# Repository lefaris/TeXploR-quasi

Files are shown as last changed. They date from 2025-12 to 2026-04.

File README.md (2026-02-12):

# TeXploR-quasi




This repository contains the system design documentation and quasistatic simulation for **TeXploR2** (Tensegrity eXploratory Robot 2), a curved-link tensegrity robot capable of dynamic rolling locomotion through internal mass shifting. This work represents a significant advancement over the [original TeXploR](https://github.com/lefaris/TeXploR-geometric).  This repo is supplemental for **System Design of Tensegrity Robot Exhibiting Non-Intuitive Behavior** accepted to IEEE ICRA 2026.

---

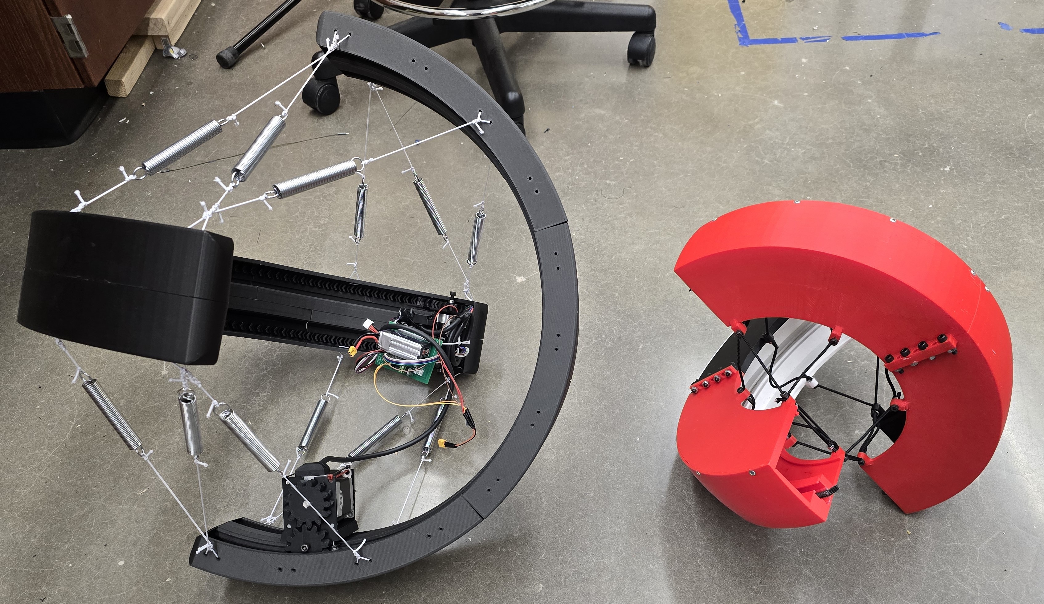
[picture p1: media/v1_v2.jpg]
TeXploR2 Comparison

*TeXploR2 (left, black) compared to the original TeXploR (right, red). TeXploR2 is completely redesigned for smoother dynamic movement regardless of shifting mass orientation (e.g., hanging upside down). The prototype is also significantly larger for additional central payload capabilities.*

## Overview

TeXploR2 is a curved-link tensegrity robot that achieves efficient rolling while maintaining stability through discontinuities present at arc endpoints. Unlike traditional straight-link tensegrity robots that contain slower toppling/walking locomotion gaits, TeXploR2's spherical-like design enables rolling.

### Key Contributions

This work showcases the system design for the TeXploR2 prototype. We also introduce non-intuitive state switching behavior that enables state transitions without requiring the shifting mass to reach arc endpoints. This enables faster state jumping and trajectory control.

- **Updated System Design**: More robust prototype capable of real-time tetherless locomotion
- **Non-Intuitive Control**: Efficient state jumping achievable along boundary lines
- **Shock Absorption**: Compliant tensegrity structure withstands impacts
- **Modular Modeling Framework and Design**: Scalable to additional curved links for finer control

---
## Demos

### Shifting Mass
TeXploR2 Shifting Mass

### Rolling Locomotion
TeXploR2 Rolling

### Impact Test
Impact Side View
Impact Other Side View

---

## Repository Structure

```
TeXploR-quasi/
├── quasistatic_modeling/   # MATLAB quasistatic simulation code
│   └── visualization/      # Simulation visualization
├── experiments/            # Motion capture data and test scripts
├── design_files/           # TeXploR2 design files
│   ├── CAD/                # Fusion files
│   └── PCB/                # KiCAD files
└── figures/                # Demo figures/videos
```

---

## Getting Started

### Prerequisites

- MATLAB R2020b or later
- Optional: Python 3.x (for hardware integration)

### Installation

1. **Clone the repository**
   ```bash
   git clone https://github.com/lefaris/TeXploR-quasi.git
   cd TeXploR-quasi
   ```

2. **Set up MATLAB path**
   ```matlab
   addpath(genpath('quasistatic_modeling'))
   ```

3. **Run quasistatic simulation**
   ```matlab
   cd quasistatic_modeling
   run('TExploRStaticsDerivationsQuasi3(0, 90)')
   ```

---

## System Design

### Mechanical Properties

| Component | Specification |
|---|---|
| **Arc Diameter** | 585mm (vs. 403mm TeXploR v1) |
| **Arc Width** | 98mm (vs. 83mm TeXploR v1) |
| **Arc Mass** | ~1,300g each |
| **Shifting Mass** | 1,150g each |
| **Mass Ratio** | 0.88:1 (shifting:arc) |
| **Material** | Onyx (Markforged) |

### Electronics

- **Controller**: Raspberry Pi Zero 2W
- **Motors**: Dual-shaft NEMA23 bipolar stepper motors (200 steps/rev)
- **Motor Drivers**: TB67S128FTG high-current carriers
- **Sensors**: 9-axis IMU (I2C)
- **Power**: 11.4V 1.5Ah LiPo battery
- **Control**: Open-loop with SSH remote control
- **Board**: Custom PCB

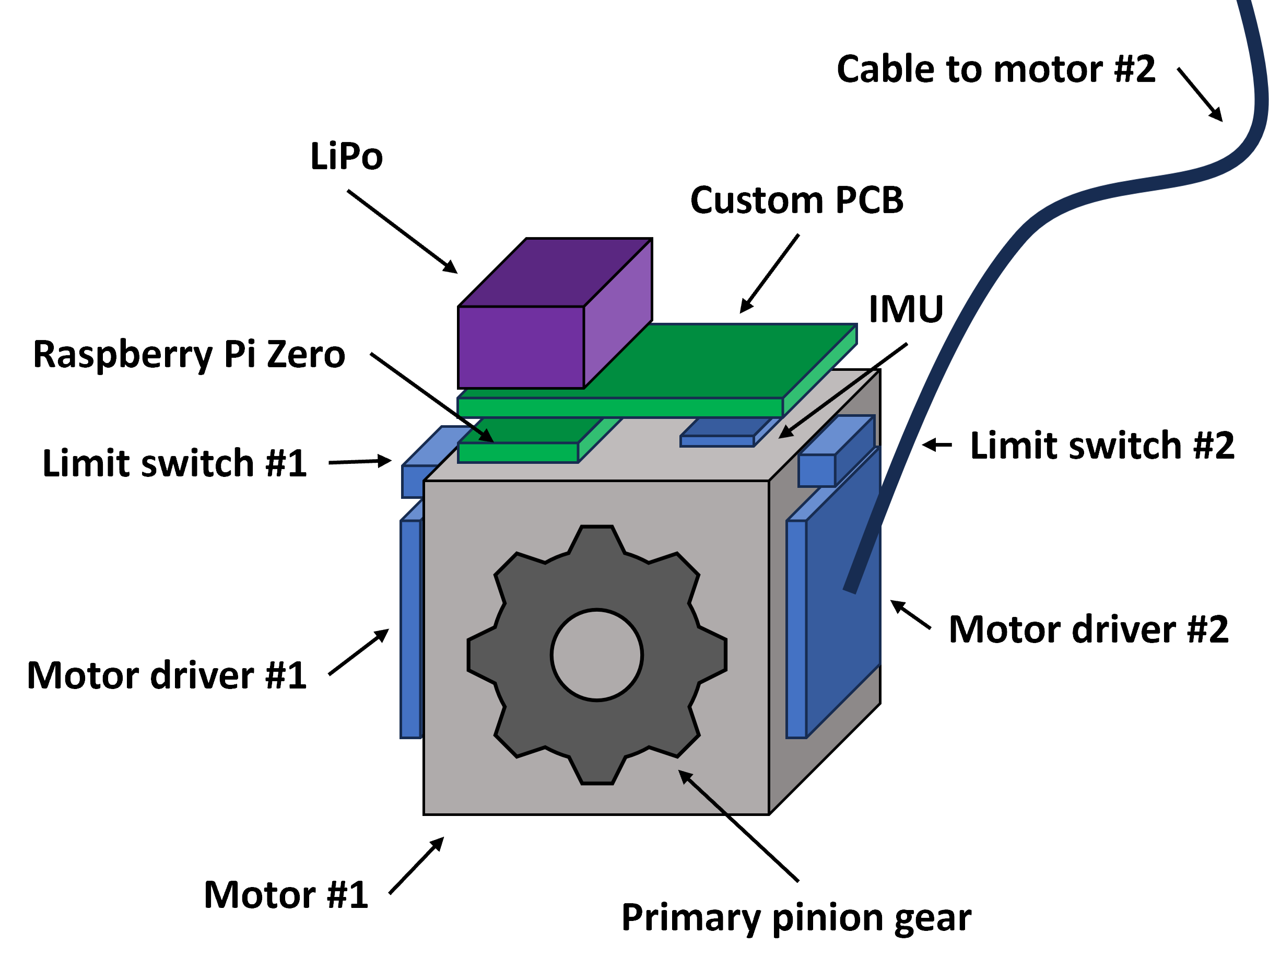
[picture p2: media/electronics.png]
TeXploR2 Electronics


### Motor Carriage Design

- **T-track latching**: For precise alignment
- **8 v-groove bearings**: (4 horizontal, 4 vertical) to prevent rotation and maintain grip
- **6 ball bearings**: For smooth rolling along arc curvature
- **Herringbone gear teeth**: For smooth power transmission at high loads

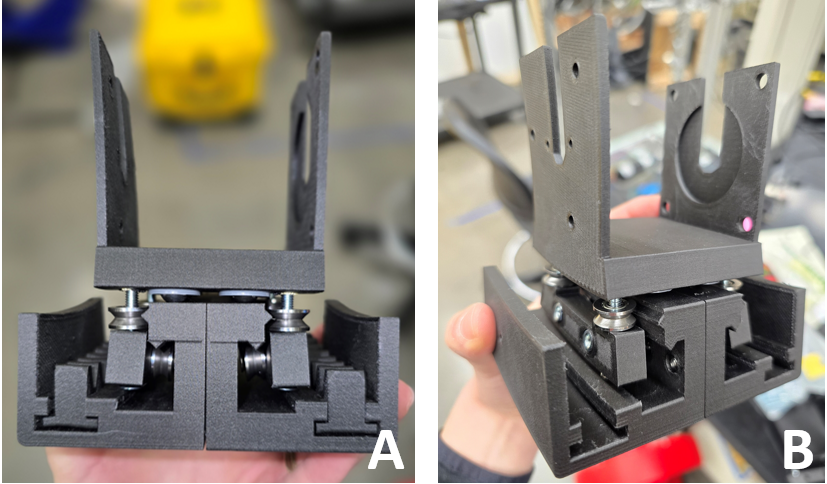
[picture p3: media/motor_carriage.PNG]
Motor Carriage


### Arc Design

- **Dual internal gear racks**: Parallel along inner curvature
- **Matching Pinion gears**: Driven by dual-shaft NEMA23 motor
- **Symmetric mass distribution**: Minimizes model discrepancies
- **98mm width**: Minimum for NEMA23 integration

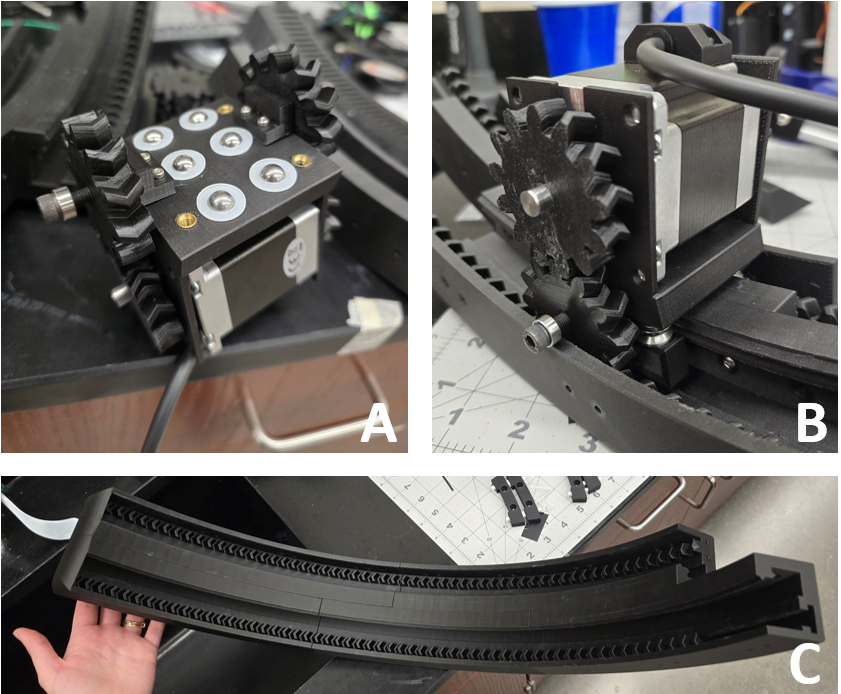
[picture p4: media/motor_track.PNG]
Motor Track


---

## Citation

If you use this work in your research, please cite both papers:

### TeXploR2 (ICRA 2026)

```bibtex
@inproceedings{texplor2_2026,
  title={System Design of Tensegrity Robot Exhibiting Non-Intuitive Behavior},
  author={Ervin, Lauren and Bezawada, Harish and Vikas, Vishesh},
  booktitle={2026 IEEE International Conference on Robotics and Automation (ICRA)},
  year={2026},
  organization={IEEE}
}
```
**arXiv preprint:** [arXiv](https://arxiv.org) (Coming Soon)

### TeXploR Geometric Modeling (IEEE RA-L 2024)

```bibtex
@article{texplor_2024,
  title={Geometric Static Modeling Framework for Piecewise-Continuous Curved-Link Multi Point-of-Contact Tensegrity Robots},
  author={Ervin, Lauren and Vikas, Vishesh},
  journal={IEEE Robotics and Automation Letters},
  year={2024},
  volume={9},
  number={12},
  pages={11066-11073},
  doi={10.1109/LRA.2024.3486199}
}
```

---

## Updates

- **January 2026:** Paper accepted to IEEE ICRA 2026
- **September 2025:** Version 2 of [TeXploR robot design](https://github.com/lefaris/TeXploR-geometric) submitted to IEEE ICRA 2026

---

## License

This project is released for academic and research purposes.

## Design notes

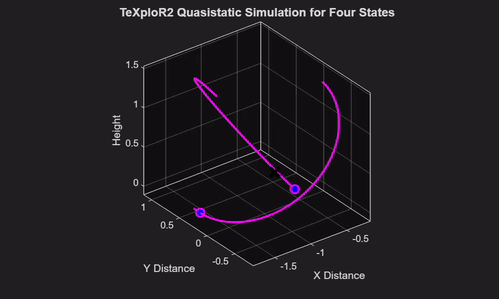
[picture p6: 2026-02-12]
quasistatic_modeling/visualization/quasiIntuitive.gif

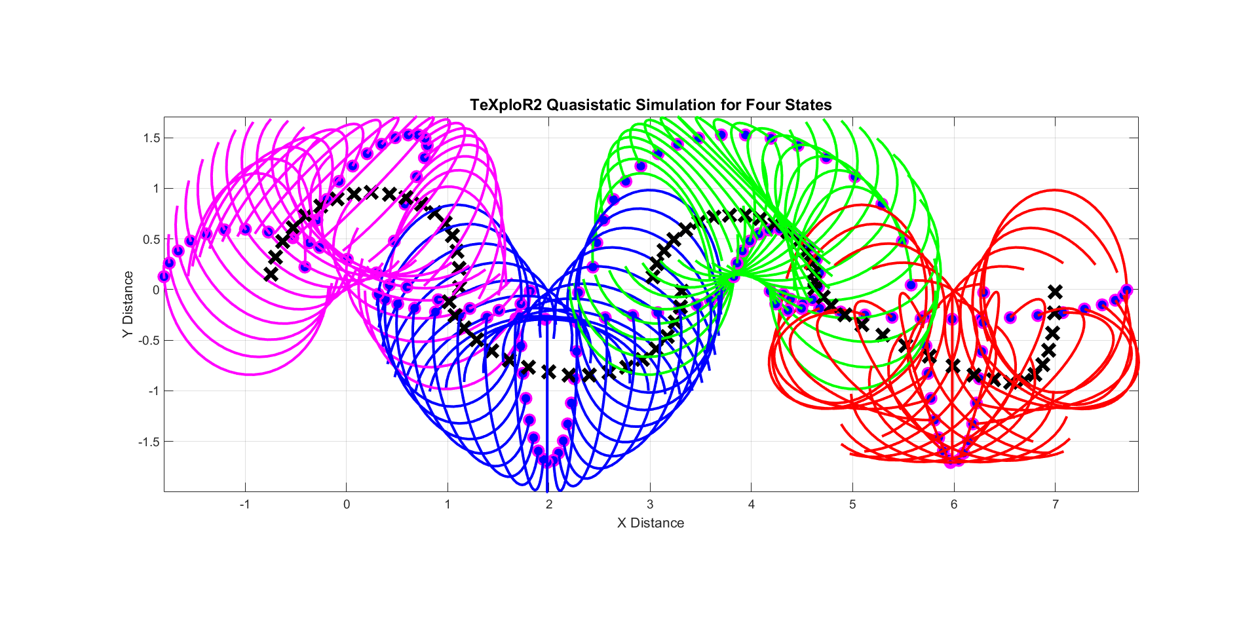
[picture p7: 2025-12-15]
quasistatic_modeling/visualization/quasi3_view2.png

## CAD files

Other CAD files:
design_files/CAD/double_helical_gear.f3d

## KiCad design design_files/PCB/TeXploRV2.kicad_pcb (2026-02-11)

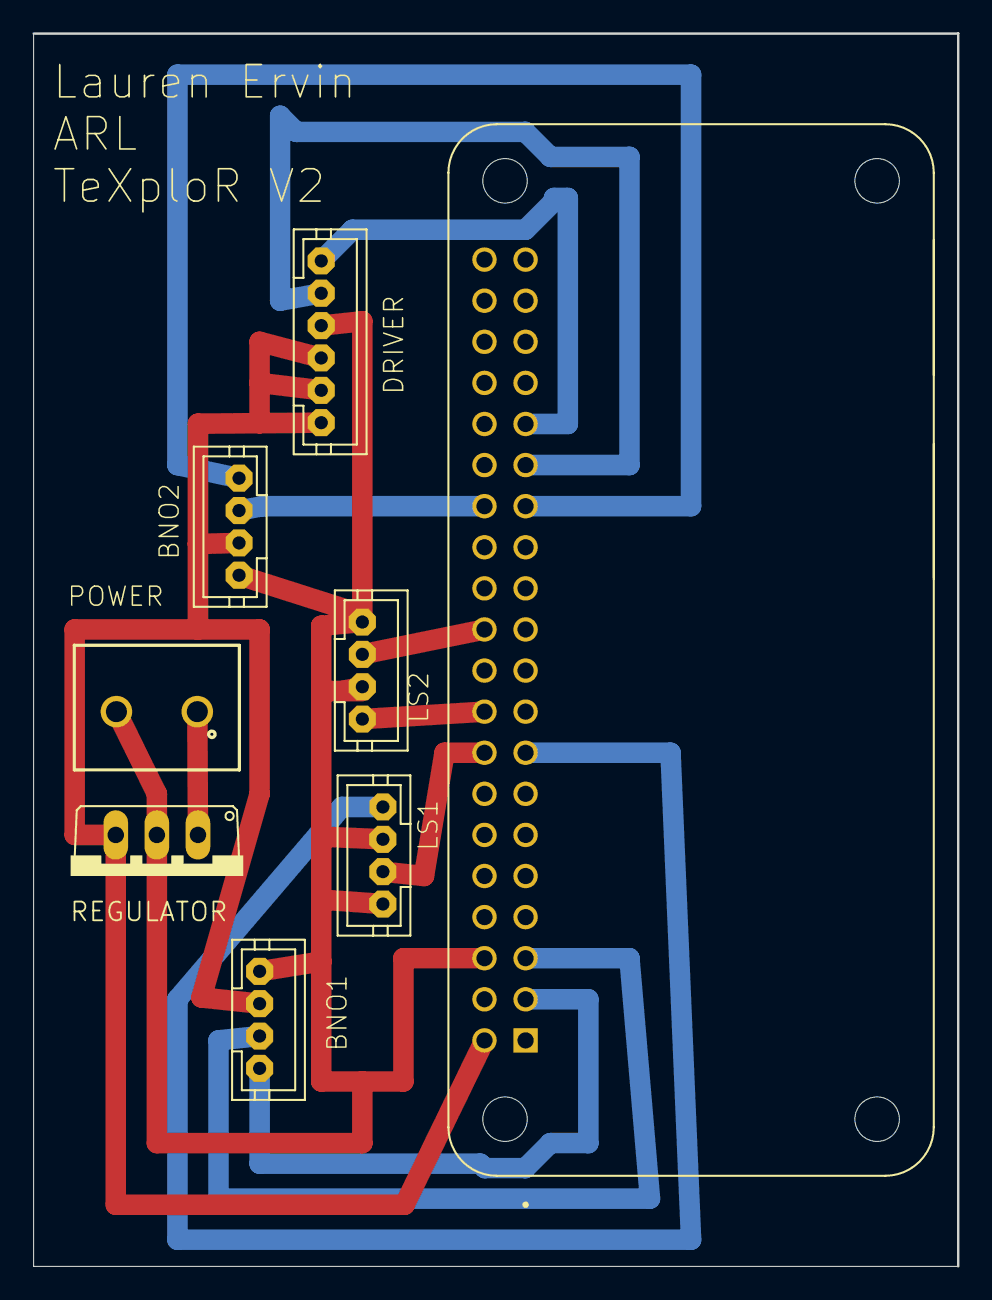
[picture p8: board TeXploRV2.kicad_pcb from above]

Board: 2 copper layers, 57.1 x 76.2 mm, 8 parts (0 on the bottom side), 13 nets.

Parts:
BNO1, BNO2: JST-PH4
DRIVER: JST-PH6
LS1, LS2: JST-PH4
POWER: 691137710002; 691137710002_16177944
REGULATOR: 7805TV; TO220V_262
U1: RASPBERRY_PI_ZERO_2_W; MODULE_RASPBERRY_PI_ZERO_2_W

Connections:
5V: BNO1.3, BNO2.3, DRIVER.1, DRIVER.2, DRIVER.3, REGULATOR.3, U1.2
DIR: DRIVER.5, U1.29
GND: BNO1.4, BNO2.4, DRIVER.4, LS1.2, LS1.4, LS2.2, LS2.4, POWER.2, REGULATOR.2, U1.6
GPIO22: LS1.1, U1.15
GPIO23: LS1.3, U1.16
GPIO24: LS2.1, U1.18
GPIO25: LS2.3, U1.22
SCL1: BNO1.2, U1.5
SCL2: BNO2.2, U1.28
SDA1: BNO1.1, U1.3
SDA2: BNO2.1, U1.27
STEP: DRIVER.6, U1.31
VIN: POWER.1, REGULATOR.1

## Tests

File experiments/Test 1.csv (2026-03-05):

Timestamp | Quat_I | Quat_J | Quat_K | Quat_Real | Acceleration_X | Acceleration_Y | Acceleration_Z
14:55.7 | 0 | 0 | 0 | 0 | 0.69140625 | -8.42578125 | 5.25
14:55.7 | 0 | 0 | 0 | 0 | 0.69140625 | -8.42578125 | 5.25
14:55.7 | 0 | 0 | 0 | 0 | 0.69140625 | -8.42578125 | 5.25
14:55.7 | 0 | 0 | 0 | 0 | 0.69140625 | -8.42578125 | 5.25
14:55.7 | 0 | 0 | 0 | 0 | 0.69140625 | -8.42578125 | 5.25
14:55.7 | 0 | 0 | 0 | 0 | 0.23046875 | -8.81640625 | 5.40234375
14:55.7 | 0 | 0 | 0 | 0 | 0.23046875 | -8.81640625 | 5.40234375
14:55.7 | 0 | 0 | 0 | 0 | 0.23046875 | -8.81640625 | 5.40234375
14:55.7 | 0 | 0 | 0 | 0 | 0.23046875 | -8.81640625 | 5.40234375
14:55.7 | -0.101928711 | 0.474975586 | -0.866699219 | 0.11315918 | 0.23046875 | -8.81640625 | 5.40234375
14:55.7 | -0.101928711 | 0.474975586 | -0.866699219 | 0.11315918 | 0.23046875 | -8.81640625 | 5.40234375
14:55.7 | -0.101928711 | 0.474975586 | -0.866699219 | 0.11315918 | 0.23046875 | -8.81640625 | 5.40234375
14:55.7 | -0.101928711 | 0.474975586 | -0.866699219 | 0.11315918 | 0.23046875 | -8.81640625 | 5.40234375
14:55.7 | -0.101928711 | 0.474975586 | -0.866699219 | 0.11315918 | 1.07421875 | -8.390625 | 5.1328125
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

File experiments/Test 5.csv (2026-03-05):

Timestamp | Quat_I | Quat_J | Quat_K | Quat_Real | Acceleration_X | Acceleration_Y | Acceleration_Z
2026-03-04 02:35:42.107155 | 0.0 | 0.0 | 0.0 | 0.0 | 0.53515625 | 9.1171875 | 2.8359375
2026-03-04 02:35:42.111987 | 0.0 | 0.0 | 0.0 | 0.0 | 0.53515625 | 9.1171875 | 2.8359375
2026-03-04 02:35:42.114521 | 0.0 | 0.0 | 0.0 | 0.0 | 0.53515625 | 9.1171875 | 2.8359375
2026-03-04 02:35:42.118206 | 0.0 | 0.0 | 0.0 | 0.0 | 0.53515625 | 9.1171875 | 2.8359375
2026-03-04 02:35:42.120288 | 0.0 | 0.0 | 0.0 | 0.0 | 0.53515625 | 9.1171875 | 2.8359375
2026-03-04 02:35:42.124864 | 0.0 | 0.0 | 0.0 | 0.0 | 0.53515625 | 9.1171875 | 2.8359375
2026-03-04 02:35:42.126877 | 0.0 | 0.0 | 0.0 | 0.0 | 0.53515625 | 9.1171875 | 2.8359375
2026-03-04 02:35:42.136676 | 0.0 | 0.0 | 0.0 | 0.0 | 0.15234375 | 9.23046875 | 2.94921875
2026-03-04 02:35:42.138344 | 0.0 | 0.0 | 0.0 | 0.0 | 0.15234375 | 9.23046875 | 2.94921875
2026-03-04 02:35:42.147141 | 0.59136962890625 | -0.04547119140625 | -0.0164794921875 | 0.804931640625 | 0.15234375 | 9.23046875 | 2.94921875
2026-03-04 02:35:42.148801 | 0.59136962890625 | -0.04547119140625 | -0.0164794921875 | 0.804931640625 | 0.15234375 | 9.23046875 | 2.94921875
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

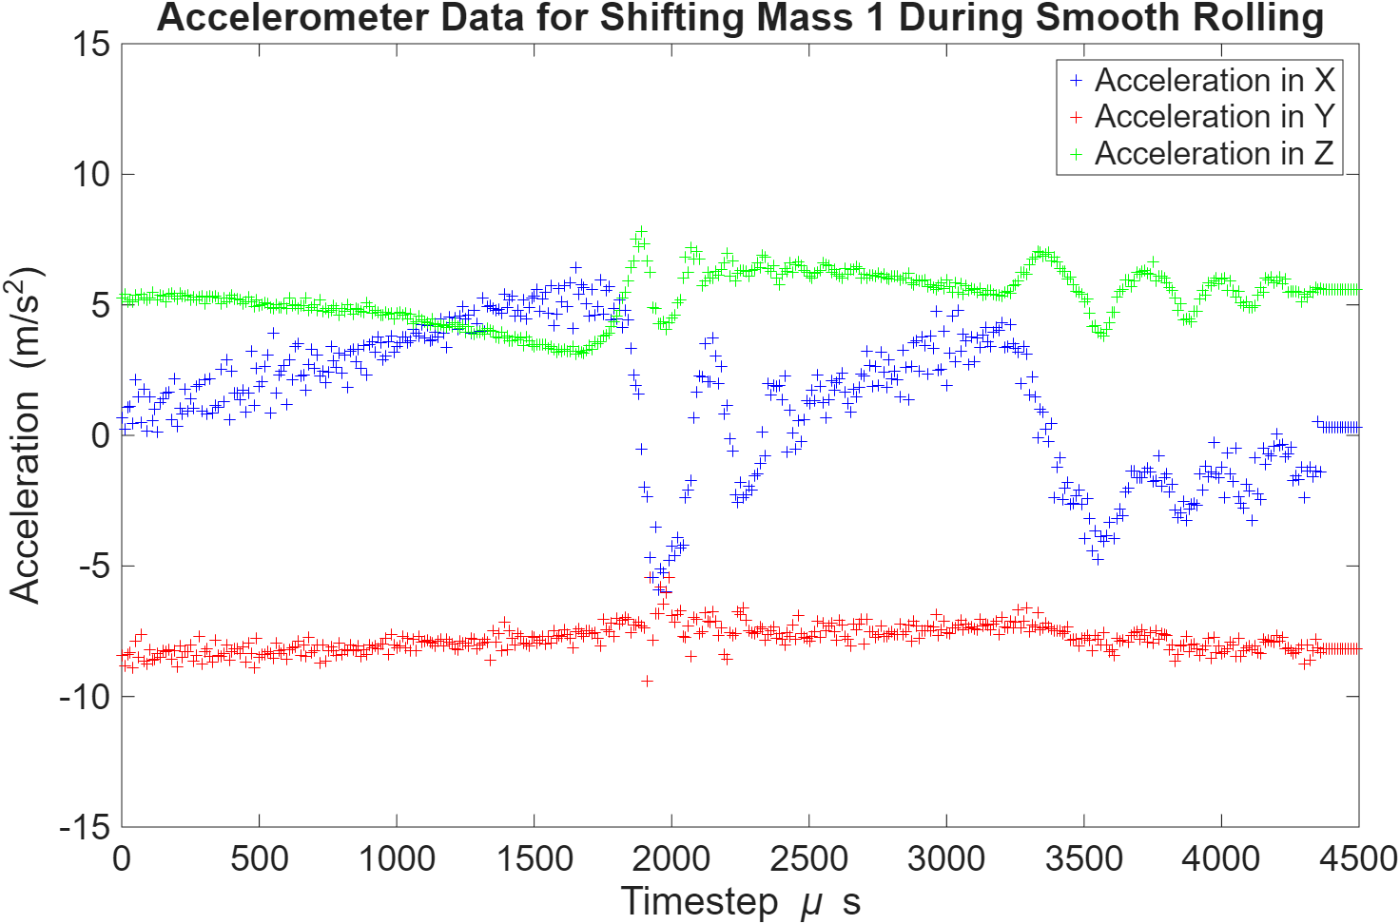
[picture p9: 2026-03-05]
experiments/rolling_accel2.png

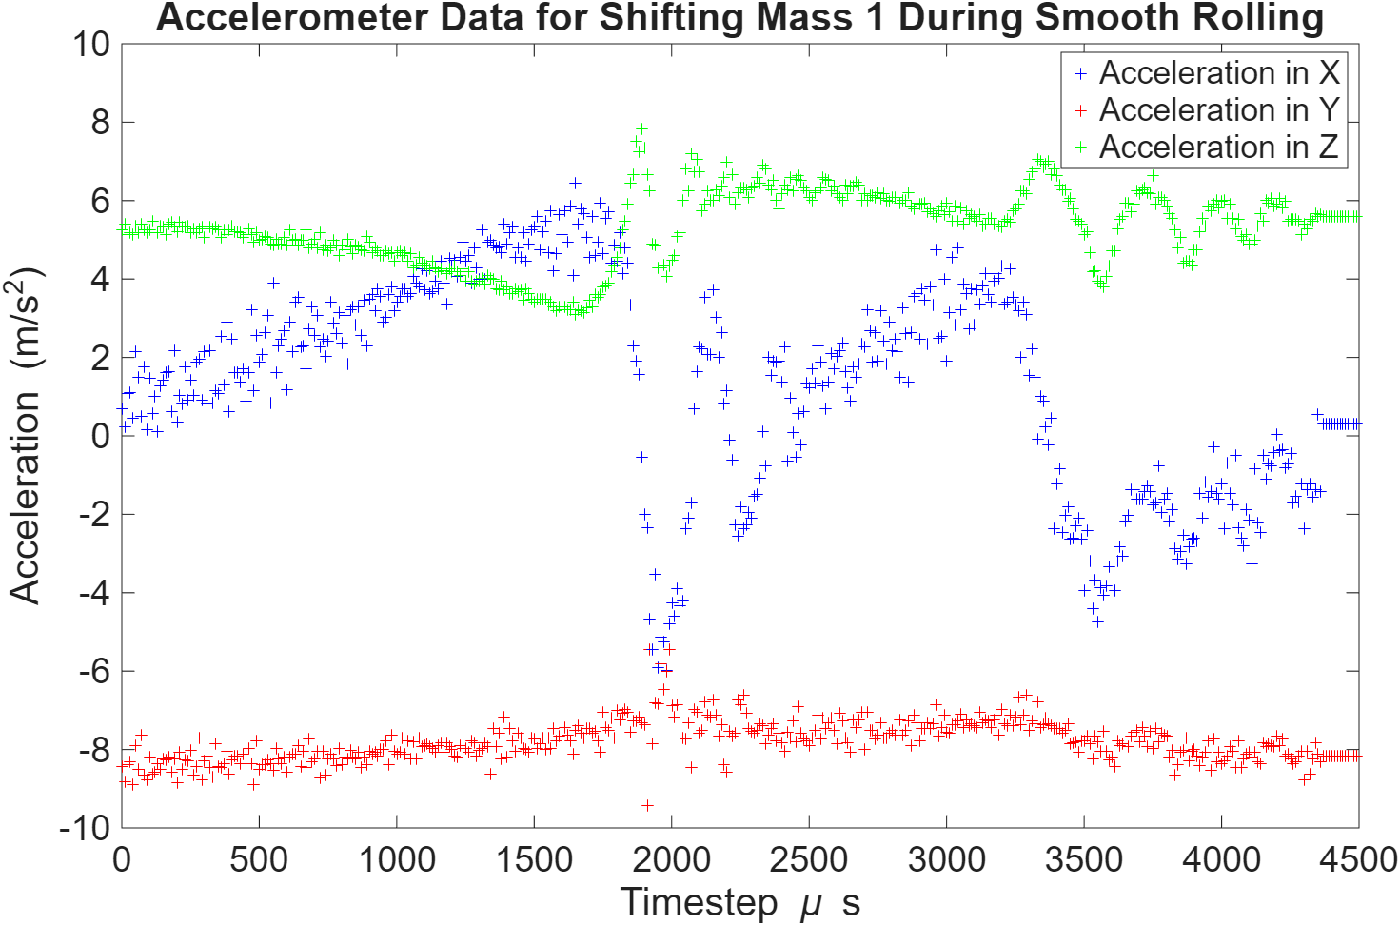
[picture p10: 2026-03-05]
experiments/rolling_accel.png

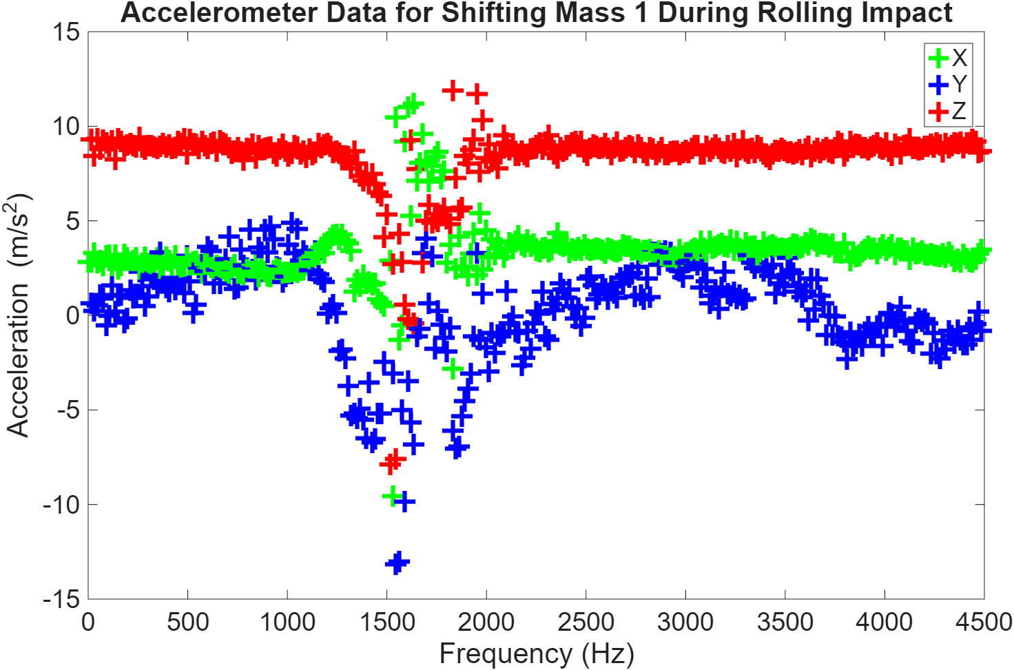
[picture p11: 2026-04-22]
experiments/impact_accel.png

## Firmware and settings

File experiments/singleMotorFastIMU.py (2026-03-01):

# Lauren Ervin
# Faster movement w/ one motor at 
# a time for TeXploR2 w/ 1 IMU

from time import sleep
import datetime
import csv
import board
import busio
from adafruit_bno055 import BNO055_I2C
import RPi.GPIO as GPIO
import os

# Shifting mass 1
DIR = 6
STEP = 5

# Shifting mass 2
DIR2 = 13
STEP2 = 12

# Clockwise/counterclockwise and steps per revolution
CW = 1
CCW = 0
SPR = 200

# GPIO setup
GPIO.setmode(GPIO.BCM)
GPIO.setup(DIR, GPIO.OUT)
GPIO.setup(STEP, GPIO.OUT)
GPIO.setup(DIR2, GPIO.OUT)
GPIO.setup(STEP2, GPIO.OUT)
GPIO.output(DIR, CW)

step_count = SPR*6 # Travel full semi-circular arc
delay = 0.002 # Controls the speed of commands inversely

i2c = busio.I2C(board.SCL, board.SDA)
bno1 = BNO055_I2C(i2c)

# Define the filename - make sure to update for each experiment!
filename = 'bno_TeXploR_test.csv'
fieldnames = ['Timestamp', 'Euler_Roll', 'Euler_Pitch', 'Euler_Yaw', 'Acceleration_X', 'Acceleration_Y', 'Acceleration_Z']

# Write CSV header
def write_header(filename, fieldnames):
    file_exists = os.path.exists(filename) and os.stat(filename).st_size != 0
    with open(filename, 'a', newline='') as csvfile:
        writer = csv.DictWriter(csvfile, fieldnames=fieldnames)
        if not file_exists:
            writer.writeheader()

# Append BNO data
def log_bno_data(filename, fieldnames):
    roll, pitch, yaw = bno.euler
    accel_x, accel_y, accel_z = bno.acceleration
    timestamp = datetime.datetime.now().strftime("%Y-%m-%d %H:%M:%S")

    data = {
        'Timestamp': timestamp,
        'Euler_Roll': roll,
        'Euler_Pitch': pitch,
        'Euler_Yaw': yaw,
        'Acceleration_X': accel_x,
        'Acceleration_Y': accel_y,
        'Acceleration_Z': accel_z
    }

    with open(filename, 'a', newline='') as csvfile:
        writer = csv.DictWriter(csvfile, fieldnames=fieldnames)
        writer.writerow(data)
            
write_header(filename, fieldnames) # Generate header

# Motor 1 travel from 0 to 180
for x in range(step_count):
    GPIO.output(STEP, GPIO.HIGH)
    log_bno_data(filename, fieldnames)
    sleep(delay)
    log_bno_data(filename, fieldnames)
    GPIO.output(STEP, GPIO.LOW)
    log_bno_data(filename, fieldnames)
    sleep(delay)
    log_bno_data(filename, fieldnames)

# Motor 2 travel from 180 to 0
sleep(0.5)
GPIO.output(DIR2, CW)
for x in range(step_count):
    GPIO.output(STEP2, GPIO.HIGH)
    log_bno_data(filename, fieldnames)
    sleep(delay)
    log_bno_data(filename, fieldnames)
    GPIO.output(STEP2, GPIO.LOW)
    log_bno_data(filename, fieldnames)
    sleep(delay)
    log_bno_data(filename, fieldnames)

# Motor 1 travel from 180 to 0
sleep(0.5)
GPIO.output(DIR, CCW)
for x in range(step_count):
    GPIO.output(STEP, GPIO.HIGH)
    log_bno_data(filename, fieldnames)
    sleep(delay)
    log_bno_data(filename, fieldnames)
    GPIO.output(STEP, GPIO.LOW)
    log_bno_data(filename, fieldnames)
    sleep(delay)
    log_bno_data(filename, fieldnames)

# Motor 2 travel from 0 to 180
sleep(0.5)
GPIO.output(DIR2, CCW)
for x in range(step_count):
    GPIO.output(STEP2, GPIO.HIGH)
    log_bno_data(filename, fieldnames)
    sleep(delay)
    log_bno_data(filename, fieldnames)
    GPIO.output(STEP2, GPIO.LOW)
    log_bno_data(filename, fieldnames)
    sleep(delay)
    log_bno_data(filename, fieldnames)

GPIO.cleanup()

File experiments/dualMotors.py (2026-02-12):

# Lauren Ervin
# Movement w/ dual motor driving
# simultaneously for sustaining 
# momentum w/ TeXploR2

from time import sleep
import RPi.GPIO as GPIO

# Shifting mass 1
DIR = 6
STEP = 5

# Shifting mass 2
DIR2 = 13
STEP2 = 12

# Clockwise/counterclockwise and steps per revolution
CW = 1
CCW = 0
SPR = 200

# GPIO setup
GPIO.setmode(GPIO.BCM)
GPIO.setup(DIR, GPIO.OUT)
GPIO.setup(STEP, GPIO.OUT)
GPIO.setup(DIR2, GPIO.OUT)
GPIO.setup(STEP2, GPIO.OUT)
GPIO.output(DIR, CW)

transition_count = SPR # Short time to speed up
step_count = SPR*5 # Travel normal speed for most of arc
delay = 0.004 # Controls the speed of commands inversely
fast_delay = 0.002 # Faster transition speed

# Motor 1 travel from 0 to 180 while 
# motor 2 moves from 180 to 150
for x in range(step_count):
    GPIO.output(STEP, GPIO.HIGH)
    sleep(delay)
    GPIO.output(STEP, GPIO.LOW)
    sleep(delay)

for x in range(transition_count):
    GPIO.output(DIR, CW)
    GPIO.output(STEP, GPIO.HIGH)
    sleep(fast_delay)
    GPIO.output(STEP, GPIO.LOW)
    sleep(fast_delay)
    GPIO.output(DIR2, CW)
    GPIO.output(STEP2, GPIO.HIGH)
    sleep(fast_delay)
    GPIO.output(STEP2, GPIO.LOW)
    sleep(fast_delay)
    

# Motor 2 continues from 150 to 0
# while motor 1 moves from 180 to 150
sleep(0.05)
GPIO.output(DIR2, CW)
for x in range(step_count):
    GPIO.output(STEP2, GPIO.HIGH)
    sleep(delay)
    GPIO.output(STEP2, GPIO.LOW)
    sleep(delay)

for x in range(transition_count):
    GPIO.output(DIR2, CW)
    GPIO.output(STEP2, GPIO.HIGH)
    sleep(fast_delay)
    GPIO.output(STEP2, GPIO.LOW)
    sleep(fast_delay)
    GPIO.output(DIR, CCW)
    GPIO.output(STEP, GPIO.HIGH)
    sleep(fast_delay)
    GPIO.output(STEP, GPIO.LOW)
    sleep(fast_delay)

# Motor 1 continues from 150 to 0
# while motor 2 moves from 0 to 30
sleep(0.05)
GPIO.output(DIR, CCW)
for x in range(step_count):
    GPIO.output(STEP, GPIO.HIGH)
    sleep(delay)
    GPIO.output(STEP, GPIO.LOW)
    sleep(delay)

for x in range(transition_count):
    GPIO.output(DIR, CCW)
    GPIO.output(STEP, GPIO.HIGH)
    sleep(fast_delay)
    GPIO.output(STEP, GPIO.LOW)
    sleep(fast_delay)
    GPIO.output(DIR2, CCW)
    GPIO.output(STEP2, GPIO.HIGH)
    sleep(fast_delay)
    GPIO.output(STEP2, GPIO.LOW)
    sleep(fast_delay)

# Motor 2 continues from 30 to 180
sleep(0.05)
GPIO.output(DIR2, CCW)
for x in range(step_count):
    GPIO.output(STEP2, GPIO.HIGH)
    sleep(delay)
    GPIO.output(STEP2, GPIO.LOW)
    sleep(delay)

for x in range(transition_count):
    GPIO.output(STEP2, GPIO.HIGH)
    sleep(delay)
    GPIO.output(STEP2, GPIO.LOW)
    sleep(delay)

GPIO.cleanup()

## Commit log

2026-02-11 Added PCB and CAD design files
    [TeXploRV2-B_Cu.gbr, TeXploRV2-B_Mask.gbr, TeXploRV2-B_Paste.gbr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]
2026-03-01 IMU collection
2026-03-05 Adding accel data
    [Test 1.csv, Test 5.csv]
2026-04-22 updated accelerometer graph
